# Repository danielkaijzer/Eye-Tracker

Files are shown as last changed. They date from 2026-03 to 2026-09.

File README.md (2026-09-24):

# Eye Tracker

A low-cost, high-precision, low-latency eye tracker prototype. A head-mounted rig pairs an IR eye camera with a forward-facing scene camera. A Python pipeline detects the pupil, calibrates a polynomial mapping from pupil pixels to scene-camera pixels, and renders the gaze locally (OpenCV).

## Platforms

- **Linux (Jetson Orin) is the research rig.** Data collection, time-synced capture and anything that depends on precise timing runs here, and it's the platform the code is developed and tested against.
- **macOS is a live-demo mode.** Plug the headset into a Mac for a quick calibration and live gaze, with no Jetson or external monitor needed. Research features may be missing or degraded there, and CI doesn't cover it, so run a quick calibration before any demo.

## Install

**Linux** (research rig; tested on Jetson Orin, JetPack 6 / Ubuntu 22.04, Python 3.10):

```
sudo apt install libeigen3-dev libopencv-dev cmake python3-dev python3-venv v4l-utils
git clone https://github.com/pupil-labs/pupil-detectors.git ../pupil-detectors
conda create -n et python=3.10 && conda activate et   # or a plain venv
pip install -r requirements.txt                 # builds pupil-detectors + pye3d from source
pip uninstall -y opencv-python                  # pupil-detectors pulls it in; it shadows opencv-contrib-python
pip install --force-reinstall --no-deps opencv-contrib-python==4.13.0.92
```

Your user must be in the `video` group to open `/dev/video*`. Cameras are opened through V4L2 with MJPG. The scene cam is picked by its USB id (`SCENE_UVC_ID` in `config.py`) because each UVC camera shows up as two `/dev/video` nodes. Exposure hotkeys go through `v4l2-ctl`. When launching over SSH, target the attached monitor with `DISPLAY=:0`. The calibration monitor runs at 100 Hz; on the Jetson that mode is persisted in `~/.config/monitors.xml`.

**macOS** (demo mode):

```
brew install eigen opencv                       # system deps for pupil-detectors
git clone https://github.com/pupil-labs/pupil-detectors.git ../pupil-detectors
pip install -r requirements.txt                 # installs the local pupil-detectors clone
```

Optional: scene-cam exposure hotkeys need the `uvc-util` binary (build steps in `requirements.txt`; terminal usage in `docs/uvc_exposure_cheatsheet.md`). Without it the app runs with the camera's default exposure.

**Both:** if the pupil-detectors build fails with `FindCython ... cython;--version failed`, CMake cached a temp build-env path from an earlier failed attempt. Delete `../pupil-detectors/_skbuild` and retry. If it still fails, install the build deps (`pip install setuptools_scm scikit-build cmake ninja cython`) and use `pip install --no-build-isolation ../pupil-detectors`.

`requirements.txt` references `../pupil-detectors` as a local path relative to the repo root; adjust the clone location or edit the path if your layout differs. `pye3d` ships from PyPI (built from source on aarch64).

**Hardware** — head-mounted rig with an IR eye camera and a forward-facing scene camera (USB UVC). Calibration draws four ArUco markers (`DICT_4X4_50`, IDs 0/1/2/3) directly onto the calibration screen.

## Running

```
DISPLAY=:0 python -m scripts.eyetracker         # Linux, in the `et` env (DISPLAY only needed over SSH)
python -m scripts.eyetracker                    # macOS demo
```

### In-app controls (eye tracker window)

| Key | Action |
| --- | --- |
| `c` | Quick calibration (3×3 grid, degree-2 polynomial). During calibration: capture the current point, or start the next pose |
| `d` | Detailed calibration (5×4 grid, degree-3 polynomial, with worst-point recapture) |
| `m` | Multi-pose calibration (one grid per head pose, aggregated into one fit — widens field-of-view coverage; press `c` to start each pose) |
| `v` | Validation capture (collect-only; writes a held-out session tagged `phase: validation` for accuracy measurement, leaves the live calibration untouched) |
| `l` | Load most recent saved calibration |
| `r` | Reset the pye3d 3D pupil model (give it ~30 s to reconverge) |
| `s` / `Esc` | During calibration: skip the current point / abort its capture and retry |
| `p`, `-` / `=` | During calibration: camera preview, marker brightness |
| `[` / `]`, `{` / `}` | Scene exposure darker / brighter, fine / coarse |
| `space` | Pause |
| `q` | Quit |

For why `m` and `v` exist and how to read the accuracy numbers, see
[`docs/calibration_coverage.md`](docs/calibration_coverage.md) and
[`docs/multipose_calibration.md`](docs/multipose_calibration.md).

## Repo layout

```
scripts/eyetracker/         # Main Python package — `python -m scripts.eyetracker`
    __main__.py             # Composition root: wires concrete classes into App
    app.py                  # Main loop, frame routing, key dispatch
    config.py               # All tunables (camera, calibration grid, smoother, ArUco)
    cameras/                # OpenCV camera sources + discovery
    pupil/                  # Pupil Labs detector + confidence/jump gates
    scene/                  # ArUco detection and screen→scene homography
    gaze/                   # Polynomial mapper, 1€ smoother
    calibration/            # State machine, sample collector, persistence
    dataset.py              # Read recorded sessions (metadata.json + labels.csv)
    display/                # Tk calibration overlay, cv2 windows

scripts/extras/             # Standalone utilities
    calibrate_scene_intrinsics.py   # ChArUco intrinsics for the scene camera
    calibrate_eye_intrinsics.py     # ChArUco intrinsics for the eye camera (app frame geometry)
    calibrate_extrinsics.py         # Eye↔scene transform from the calibration jig (hand-eye solve)
    generate_charuco_board.py       # Screen board PNG for the above; printable jig boards (PDF)
    charuco_boards.py               # Board specs shared by the generator and calibration scripts
    measure_gaze_accuracy.py        # Accuracy binned by eccentricity; held-out validation sessions

docs/                       # Implementation notes, citations, architecture
    findings.md                     # What we've measured, decided, or learned (dated)
    polynomial_gaze_mapping.md      # How the pupil→scene fit works end-to-end
    loo_error_notes.md              # Leave-one-out error: what it measures, past regression
    calibration_coverage.md         # The coverage problem + eccentricity validation tooling
    multipose_calibration.md        # Multi-pose calibration: widening FOV coverage
    uvc_exposure_cheatsheet.md      # macOS uvc-util camera controls from the terminal
    data_collection.md              # Fields the data-collection pipeline captures
    dataset_format.md               # On-disk format for sessions + calibration artifacts
    citations/                      # references.bib + references.tex

data/                       # Recorded calibration sessions (gitignored)
3d-files/                   # OpenSCAD camera mounts (see its README)
requirements.txt            # Python deps (OpenCV, numpy, pupil-detectors)
```

## Pipeline

```mermaid
graph TD
    subgraph Hardware ["Head-mounted rig"]
        EYE[IR eye camera] --> CAP[OpenCV capture]
        SCN[Scene camera] --> CAP
    end

    subgraph Pipeline ["Python (scripts/eyetracker)"]
        CAP --> PD[Pupil Labs 2D detector + pye3d]
        PD --> GATE[Confidence + jump gates]
        GATE --> POLY[Polynomial gaze mapper]
        CAP --> ARUCO[ArUco screen-corner detection]
        ARUCO -. calibration only .-> CAL[Calibration routine<br/>screen→scene homography]
        CAL --> POLY
        POLY --> SMOOTH[1€ smoother]
    end

    subgraph Output
        SMOOTH -->|cv2 windows| CV[Display]
    end
```

See [`docs/polynomial_gaze_mapping.md`](docs/polynomial_gaze_mapping.md) for the math behind the pupil→scene fit and why the homography only shows up during calibration.

## Code style

- **Python** — [PEP 8](https://peps.python.org/pep-0008/). Enforced by `flake8` in CI (`.github/workflows/linter.yml`): blocking on `E9`/`F63`/`F7`/`F82` (syntax errors, undefined names), with line length 127 and McCabe complexity 10 as non-blocking warnings. Public-facing modules, classes, and functions carry docstrings.

## Design & architecture

- **External references** — catalogued in [`docs/citations/references.bib`](docs/citations/references.bib)

## Maintainer 

Daniel Kaijzer

## Prior contributors

Cody Lam, Ethan Shim, Harwin He, Roselio Ortega

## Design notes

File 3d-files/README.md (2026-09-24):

# 3D-printed camera mounts

Parametric OpenSCAD designs for the eye and scene camera mounts. Open a `.scad`
file, set `show = ...` near the top, then press F5 to preview or F6 to render and
export an STL. Hardware dimensions are in [MEASUREMENTS.md](MEASUREMENTS.md).

## Current designs (printed and in use)

| Camera | File | Notes |
|---|---|---|
| Eye (UC-844 Rev.B, IR) | [`eye_cam/uc844_mount_v9_DK.scad`](eye_cam/uc844_mount_v9_DK.scad) | Frame + two arms; clamps to the rod with the stock white clips. Needs `clip_ref.stl` in the same folder. |
| Scene (HUAQUE HQ-L103) | [`scene_cam/scene_cam_top_mount_v2.scad`](scene_cam/scene_cam_top_mount_v2.scad) | Backing plate + parametric `rod_clip()`, so no STL import is needed. |

When a new version replaces one of these, move the old file into `archive/`.

## Calibration jig

The eye↔scene extrinsics jig isn't 3D printed. It's three stainless steel sheets held at
roughly 90° with L brackets, with printed ChArUco boards pasted on
(`scripts/extras/generate_charuco_board.py --board print`) so the eye cam and the scene cam
each see a board on a different sheet. The angles don't need to be exact: the extrinsics
solver only needs the jig to be rigid (`scripts/extras/calibrate_extrinsics.py`; its
docstring has the capture workflow). An earlier 3D-printed design was never built; it's in
git history.

## Archive

`archive/` keeps earlier iterations for reference. They aren't maintained.

- `archive/eye_cam/`: `uc844_mount_v1`–`v8`, `glasses_rod_adapter.scad` (the peg
  adapter that v3's integrated clamp replaced), the v6 design notes, and the original Fusion STEP bottom mount.
  v7 and v8 import `../../eye_cam/clip_ref.stl`.
- `archive/scene_cam/`: `scene_cam_top_mount_v1.scad` and the original Fusion
  STEP top mounts (`top_mount_step/`, v1–v3.3).

## Design notes

- 60° seems to be the right angle for the internal eye cam.
- The backs of the mounts should be perforated for airflow. Consider a way to
  add thermal paste to help cool the PCBs.

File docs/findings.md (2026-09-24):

# Findings

What we've measured, decided, or learned the hard way, so it carries across
sessions and machines. One or two lines each, newest first within a section,
with a pointer (→) to the doc or code that holds the detail.

When a finding stops being true, don't delete it: mark it **Superseded** with the
date and what replaced it. "We tried X and it didn't work" is often the most
useful part. Entries marked *unverified* haven't been confirmed on the rig.

## Gaze model and calibration

- 2026-09-24 · Scene cam horizontal FOV is ~54° (fx 1894.7 px at 1920 wide), so
  multi-pose calibration is capped by when a corner marker leaves the frame, not
  by the lens. → `TODO_multipose_coverage.md`
- 2026-09-23 · Calibration labels, fit and live prediction check out (quick
  9-point LOO ~14–28 px). Remaining error is physical: gaze is only exact at the
  calibration depth (eye↔scene parallax), and the pupil-only mapping is very
  slip-sensitive (a ~40 px pupil shift between runs moved gaze ~900 px).
  → `TODO.md` (Accuracy)
- 2026-07-13 · *Unverified:* undistorting marker corners before `findHomography`
  cut geometric error at non-anchor points by ~1.2 px in a synthetic test with the
  real distortion coefficients. → branch `use-intrinsics-for-homography`
- 2026-06-29 · A half-finished hat-matrix LOO refactor once returned all-zero LOO
  errors, silently breaking recapture targeting and accuracy reports.
  → `docs/loo_error_notes.md`, `tests/test_polynomial_loo.py`
- 2026-06-06 · **Decision:** the roadmap is polynomial → CNN (eye image in, gaze
  point out), with no 3D-model step. First, data collection whose sessions stay
  usable across rig changes.
- Before 2026-06 · Polynomial ceiling: a narrow central grid gave 0.39° avg /
  0.94° max LOO; a wider grid made the fit worse everywhere (~1.56° avg). Don't
  tune the polynomial (degree, grid size, point count). → `docs/calibration_coverage.md`
- Standing · Benchmark: Pupil Labs Neon, ~0.5–1° (model-based, multi-glint, slip
  correction).

## Cameras

- 2026-09-24 · The app center-crops eye frames to 4:3 and resizes them to 640x480
  before pupil detection, so pupil coordinates and saved eye images are 640x480 in
  any mode. But the eye cam's native mode isn't requested (driver default), and
  `EYE_CAM_FOV_DEG` (80°) is the old Sonix lens; it feeds pye3d's focal length and
  `metadata.json`. → `config.py`, `TODO.md`
- 2026-09-24 · Eye cam illumination: one hand-soldered IR LED above the lens
  (off-axis): dark pupil, single glint, no retroreflection. → `3d-files/MEASUREMENTS.md`
- 2026-09-23 · OV9281 manual exposure works over UVC on Linux (0.5–9.9 ms
  verified). In auto mode it doesn't report the exposure it picked.
  → `docs/timestamping.md` (on branch `timestamping`)
- 2026-07-15 · OV9281 caps at 120 fps in every mode (MJPG 320x240 to 1280x800 at
  100/120 fps; YUYV only 10 fps; no 30 fps mode). Faster needs other hardware.
- 2026-07-15 · Trap (macOS): `ffmpeg -f avfoundation` "negotiates" 120 fps but
  delivers ~83. Always measure delivered fps.
- 2026-07-15 · The OV9281 reuses the Sonix bridge's USB id `0x0c45:0x6366`; tell
  them apart by serial (UC762). Camera indexes shift between enumerations, so
  select cameras by USB id, not index.
- 2026-06-28 · The scene cam (Realtek OV5640) is manual-exposure only;
  `exposure-time-abs` is the real brightness lever and `gain` only scales output.
  → `docs/uvc_exposure_cheatsheet.md`
- **Superseded 2026-06-28** · "Scene exposure-time is cosmetic." It was tested in
  auto mode, where UVC ignores exposure writes.
- **Superseded 2026-09** · "The eye cam's exposure can't be controlled." True only
  of the retired Sonix GC0308, whose auto-exposure ran internally.
- 2026-06-08 · uvc-util reports success even when a camera ignores or clamps a
  write, so every set is read back. On macOS, OpenCV can't set exposure at all.
  → `cameras/uvc_util.py`

## Timing and sync

- 2026-09-23 · Eye−scene timestamp offset (flash test): 4.8 ms, ±0.3 ms run to
  run, ~±2 ms systematic. Rerun if exposure or cameras change.
  → `docs/timestamping.md` (on branch `timestamping`)
- 2026-09-23 · The 5.15 kernel's UVC hardware timestamps are broken for the eye cam
  (its bridge reports a free-running counter; stamps drifted ~2600 ppm and jumped
  >100 ms), so PTS/SCR are converted in userspace. → `docs/timestamping.md`
  (on branch `timestamping`)
- 2026-09 · Without a grabber thread, V4L2 hands back the oldest queued frame: eye
  frames were 130–275 ms stale on the Jetson. → `cameras/opencv_source.py`
- 2026-09-24 · **Decision:** no streaming the rig's video to another machine for
  calibration or display for now. Calibration-dot onsets would then happen on a
  different machine's clock, bringing back the cross-machine sync problem.
  (`linux_cam_stream.py` removed; it's in git history.)
- 2026-09 · **Decision:** research capture runs on Linux. On macOS, raw UVC
  timestamps need root and exclusive device access, which rules out OpenCV
  capture. macOS stays a live-demo mode. → `README.md` (Platforms)

## Calibration jig and rig geometry

- 2026-09-24 · Synthetic check of the hand-eye extrinsics solve: exact recovery on
  clean data; 0.29° / 2.3 mm error with 0.2° / 0.5 mm per-pose noise over 20 pairs.
  → `tests/test_extrinsics_solve.py`
- 2026-09-24 · Eye-side board: at eye distance (~45–50 mm) 5 mm squares give
  45–113 ChArUco corners per frame in a synthetic render, vs ~6 for 15 mm squares.
  Refocusing the M12 lens changes the intrinsics by a few percent, so calibrate at
  eye focus. The print dictionary has only 1000 marker IDs, so board sizes are
  capped. → `scripts/extras/charuco_boards.py`, `tests/test_charuco_boards.py`
- 2026-09-24 · *Unverified:* many inkjet inks are nearly invisible in IR, so
  laser-print boards the eye cam must see.
- 2026-09-24 · **Decision:** the 3D-printed jig was abandoned for three stainless
  steel sheets at ~90° with pasted ChArUco boards. The hand-eye solve only needs
  the jig rigid, not measured. → `3d-files/README.md`, `calibrate_extrinsics.py`
- 2026-05 · Tape-measured camera offsets: ~50 mm lateral, 13 mm depth, 50 mm
  vertical (~72 mm baseline), on the old mounts. Re-measure before relying on them.

## Data

- 2026-09-24 · The pre-migration calibration history (27 Sonix-era sessions, 352
  pupil/target pairs, no images) is kept only on the Mac at `data/legacy/`, not in
  git.
- 2026-06-06 · Persistence moved off `.npz` to JSON + CSV (`calibration.json`,
  per-session `metadata.json` + `labels.csv`). → `docs/dataset_format.md`

## Scope

- 2026-09-24 · **Decision:** no frontend until the tracking fundamentals work. The
  paused Next.js dashboard and its tools were removed (they're in git history).

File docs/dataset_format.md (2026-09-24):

# Dataset & calibration on-disk format

The pipeline records calibration/collection sessions as a **dataset of record** for
later analysis and CNN training. Each artifact uses the format that fits its job —
JSON for small structured/provenance data, CSV for append-during-capture sample
rows, image files for frames, Parquet only at consumption time.

## Layout

```
data/calibration/
  session_<ts>/
    metadata.json            # per-session record (intrinsics, extrinsics, provenance)
    labels.csv               # one row per accepted sample
    fixNN_sampleNN.png       # eye-cam frame
    fixNN_sampleNN_scene.png # scene-cam frame
  combined.parquet           # planned: cache for whole-dataset training loads
scripts/eyetracker/
  calibration.json           # live polynomial model restored at runtime
  scene_intrinsics.json      # scene-cam intrinsics (K, dist)
  eye_intrinsics.json        # eye-cam intrinsics, in the app's cropped 640x480 frames
rig_calibrations/
  <rig_id>.json              # written by scripts/extras/calibrate_extrinsics.py
```

## Artifacts

### `calibration.json` — the live model
Just what the runtime needs to restore the mapper. Raw samples are **not** stored
here; they live in the source session's `labels.csv` (named via `source_session`).

```json
{ "coord_space": "scene", "timestamp": 0.0, "source_session": "session_<ts>",
  "scene_size": [w, h], "screen_size": [w, h],
  "model": { "type": "polynomial", "degree": 2, "coeffs_x": [...], "coeffs_y": [...] } }
```

### `session_<ts>/metadata.json` — the dataset record
Self-contained: each session inlines a snapshot of the active intrinsics/extrinsics
so it stays interpretable even if the cameras or central calibration files change.
Fields the pipeline does not yet produce are `null` placeholders (filled later by the
extrinsics jig and richer per-frame capture).

```json
{ "session_id": "session_<ts>", "created_at": "<iso>", "timestamp": 0.0,
  "phase": "calibration",
  "subject_id": null, "glasses": null, "headset_model_version": null, "kappa_deg": null,
  "software": { "pupil_detector": null, "pye3d": null, "app_git_sha": null },
  "screen":   { "width": w, "height": h },
  "scene_cam":{ "width": w, "height": h, "fps": null, "identifier": null },
  "eye_cam":  { "width": w, "height": h, "fps": null, "fov_deg": 80.0, "identifier": null },
  "aruco":    { "dict_name": "...", "dict_id": n, "marker_px": n, "quiet_zone_px": n,
                "ids": [...], "screen_centers": [[x, y], ...] },
  "superseded_fixation_ids": [],
  "rig_calibration_id": null,
  "intrinsics": { "eye": null, "scene": { "K": [[...]], "dist": [...], "reproj_rms": n } },
  "extrinsics": null,
  "fit": { "degree": 2, "n_points": n, "loo_avg_px": n, "loo_max_px": n } }
```

### `labels.csv` — per-sample ground truth
Columns (see `LABELS_CSV_HEADER` in `calibration/persistence.py`):
`image_path, fixation_id, x_screen, y_screen, pupil_x, pupil_y, confidence,
timestamp, scene_target_x, scene_target_y`. Appended row-by-row during capture so a
mid-session crash keeps what was already written. `fixation_id` is unique within a
session (one per capture attempt, so rejected/aborted attempts leave gaps) and
names the images (`fix<id>_sample<n>.png`). A screen point can appear under
several ids: once per pose in multi-pose, and twice when the detailed routine
recaptures it. `metadata.json`'s `superseded_fixation_ids` lists the pass-1
ids a recapture replaced; drop them to reproduce the live fit. Sessions from
before 2026-09-23 reused ids across poses/recapture passes (and overwrote those
images), so their `fixation_id` is unreliable there. Richer per-frame fields
(ellipse params, pye3d 3D vectors, normalized-image paths) from
`docs/data_collection.md` are added as the pipeline starts producing them.

### `rig_calibrations/<rig_id>.json` — camera-rig calibration (planned)
Written by `scripts/extras/calibrate_extrinsics.py` from a jig capture. Sessions don't
reference it yet: `rig_calibration_id` and `extrinsics` in `metadata.json` are still
null (see `TODO.md`).

```json
{ "rig_id": "<ts>", "created_at": "<iso>", "notes": null,
  "intrinsics": {
    "eye":   { "K": [[...]], "dist": [...], "image_width": 640, "image_height": 480,
               "reproj_rms": r, "source": "eye_intrinsics.json" },
    "scene": { ...same keys... } },
  "extrinsics_eye_to_scene": {
    "R": [[...]], "t": [...], "units": "mm", "method": "calibrateRobotWorldHandEye/SHAH",
    "residual_rot_deg": { "mean": x, "max": x }, "residual_trans_mm": { "mean": x, "max": x } },
  "capture": { "n_pairs": n, "pose_diversity_deg": x, "eye_board": "small",
               "scene_board": "large", "board_b_to_a": { "R": [[...]], "t": [...] } } }
```

`extrinsics_eye_to_scene` maps eye-cam coordinates to scene-cam coordinates:
`p_scene = R @ p_eye + t`, in mm. The intrinsics are copied in so the record is
self-contained; the eye intrinsics describe the app's processed eye frames (4:3 crop,
resized to 640x480), not the camera's native mode.

## Loading for analysis / training

`scripts/eyetracker/dataset.py`:
- `load_session(dir) -> (metadata, DataFrame)` — one session.
- `session_dirs(root)` — list every `session_<ts>/` under a root.

Planned (TODO in `dataset.py`, build with the CNN training loop): `load_all` to
concatenate all sessions + cache `combined.parquet`, and an image-loading layer that
joins each row's `image_path` to its eye frame.

`scripts/extras/measure_gaze_accuracy.py --session <dir>` refits the polynomial from
a session and reports LOO error in px and degrees.

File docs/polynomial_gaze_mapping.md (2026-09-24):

# Polynomial Gaze Mapping

How we turn a pupil pixel from the eye camera into a gaze pixel in the scene camera.

## Goal

Given a pupil center `(px, py)` in eye-camera pixels, predict where in the scene-camera image the user is looking — `(scene_x, scene_y)`.

## Why a polynomial?

The eye is a sphere, the cornea bulges, the eye camera sits at an off-axis angle, and the pupil moves on a curved manifold as gaze sweeps the world. The mapping `(px, py) → (scene_x, scene_y)` is not linear, but over the limited range of pupil motion it is smooth and well-approximated by a low-degree polynomial.

We use a 2nd-degree bivariate polynomial. The feature row (`_build_features` in `scripts/eyetracker/gaze/polynomial.py`) is:

```
φ(px, py) = [1, px, py, px², py², px·py]
```

Six terms, so:

```
scene_x = a₀ + a₁·px + a₂·py + a₃·px² + a₄·py² + a₅·px·py
scene_y = b₀ + b₁·px + b₂·py + b₃·px² + b₄·py² + b₅·px·py
```

Two completely independent fits — one for `x`, one for `y`. 12 unknowns total (6 per axis).

This doc walks through degree 2, which quick calibration (`c`) uses. Detailed (`d`) and multi-pose (`m`) calibration use degree 3 (10 terms per axis, cubic terms added); the same reasoning applies with 10 in place of 6.

### 6 coefficients vs. 9 calibration points

A potential point of confusion: quick calibration (`c`, `CALIB_QUICK_*` in `scripts/eyetracker/config.py`) is a 3×3 grid = **9 fixation targets**, but each polynomial only has **6 coefficients**. Why so many points if there are only 6 unknowns?

Because we are *deliberately overdetermined*. Each fixation gives one `(px, py) → scene_x` equation and one `(px, py) → scene_y` equation. With 9 fixations we have 9 equations per polynomial in 6 unknowns — more equations than unknowns. There is generally no exact solution; instead `np.linalg.lstsq` finds the 6 coefficients that minimize the total squared error across *all* 9 points simultaneously.

The 3 extra equations are not waste, they are noise averaging:

- The pupil center is noisy (per-frame jitter, ellipse fitting variance).
- The ArUco-derived label is noisy (marker detection shake).
- The user does not fixate perfectly.

If we used exactly 6 points, the polynomial would pass through every label exactly — including their noise. Those 6 coefficients would chase noise instead of true geometry, and predictions on new pupil positions would be worse. With 9 points the fit is forced to compromise, which pulls it toward the *underlying* pupil-to-scene relationship.

The hard minimum is 6 points (the `n < 6` guard). Below that the system is underdetermined — infinitely many polynomials fit. Above 6, more is generally better up to a point of diminishing returns.

## What calibration collects

For each fixation point we need a pair:

- **Input**: pupil center `(px, py)`, median-filtered over a small per-fixation buffer (`SampleCollector` in `scripts/eyetracker/calibration/collector.py`).
- **Label**: where that fixation target actually appeared in the scene-cam image.

The label is the tricky part — that's where the homography enters.

## Where the homography fits in

We show a red dot at screen-pixel `(tx, ty)` on a monitor. The scene camera knows nothing about the screen — it just sees a 2D image of the world. We need to know: "the dot is at screen-pixel `(tx, ty)`; where in the scene-cam frame is that point right now?"

A flat screen viewed from an arbitrary angle becomes a quadrilateral in the camera image. The screen-plane → camera-image mapping is exactly a **homography** — a 3×3 matrix in projective coordinates.

Four ArUco markers are pinned at the screen corners. In `ArucoHomography._homography_from` (`scripts/eyetracker/scene/aruco_homography.py`):

```python
H, _ = cv2.findHomography(screen_pts, scene_pts, method=0)
```

- `screen_pts` — the 4 marker centers in screen pixels (we drew them, so we know exactly where).
- `scene_pts` — the 4 marker centers detected in the scene-cam image.

OpenCV solves for the 3×3 `H` such that for any screen point `(tx, ty)`:

```
[u·w, v·w, w]ᵀ = H · [tx, ty, 1]ᵀ
scene_u = u·w / w
scene_v = v·w / w
```

That projection happens in `CalibrationRoutine.tick()` (`scripts/eyetracker/calibration/routine.py`). We recompute `H` on every calibration frame because the user's head moves and the screen-to-scene projection drifts. The resulting `(target_u, target_v)` is the "ground truth" scene-cam pixel for each pupil sample.

## The calibration loop

For each fixation:

1. User stares at the red dot at screen-pixel `(tx, ty)`.
2. Pupil pipeline gives us `(px, py)`.
3. ArUco gives us `H` for this frame.
4. `(target_u, target_v) = H · (tx, ty)` — the dot's location in scene-cam pixels.
5. Median-filter both over a few frames (`SampleCollector`) to get one clean `(pupil_median, scene_median)` pair.

After all accepted fixations (9 from the quick grid, fewer if the user skipped any) we have matched arrays of `pupil_pts` and `scene_pts`.

## The fit

In `PolynomialGazeMapper.fit()` (`scripts/eyetracker/gaze/polynomial.py`): build the design matrix `A` (n rows × 6 columns, each row is `φ(px, py)`), and target vectors `bx` (n scene-x labels) and `by` (n scene-y labels). Solve two least-squares problems:

```python
cx, _, _, _ = np.linalg.lstsq(A, bx, rcond=None)   # 6 coeffs for scene_x
cy, _, _, _ = np.linalg.lstsq(A, by, rcond=None)   # 6 coeffs for scene_y
```

`np.linalg.lstsq` minimizes `||A·c − b||²` — closed-form, no iteration. With 9 points and 6 unknowns the residual sum of squares has 3 degrees of freedom (n − p = 9 − 6), which is what lets the fit average out per-point noise instead of memorizing it. The hard minimum is 6 points (the `n < 6` guard); below that the system is underdetermined.

## Leave-one-out error

Also in `PolynomialGazeMapper.fit()`: refit using `n−1` points, predict the held-out one, measure pixel error in scene-cam space. Average and max over all `n` rounds. This is more honest than training residuals — with 6 unknowns and only 9 points, training residuals would underestimate true error because the fit is close to interpolating its own training set.

## Prediction at runtime

After calibration the homography is gone — it did its job (labeling) and is no longer needed. At runtime (`PolynomialGazeMapper.predict()`):

```python
feat = [1, px, py, px², py², px·py]
scene_x = feat · coeffs_x
scene_y = feat · coeffs_y
```

12 multiply-adds per frame. The polynomial takes pupil pixels and gives scene-cam pixels directly — no homography at inference, because calibration baked the geometry into the polynomial coefficients.

## Mental model

- **Polynomial** — "given a pupil pixel, where is the gaze in the scene cam?" The model used forever after calibration.
- **Homography** — "given the dot on the screen, where is it in the scene cam right now?" Only used during calibration to manufacture training labels. It's what turns "look at this screen pixel" into "the eye is fixating that scene pixel."

If the user moves their head, the homography changes (the screen appears somewhere different in the scene cam), but the polynomial doesn't care. Pupil-pixel-to-scene-cam-pixel is a property of how the eye + cameras are rigged together on the headset, invariant to where the user is standing.

The one assumption currently baked in: the eye and scene cameras are fixed relative to each other (head-mounted rig). If the rig flexes, the polynomial drifts and recalibration is needed.

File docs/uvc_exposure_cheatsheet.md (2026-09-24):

# UVC camera control cheat sheet (macOS)

Quick reference for driving the rig's cameras with **uvc-util** from the command
line, independent of the app. OpenCV/AVFoundation can't set exposure on macOS, so
this is the only working path. On Linux, use `v4l2-ctl` instead.

## Setup

The binary lives at `/opt/homebrew/bin/uvc-util` (on PATH). Every command selects
a camera by its USB **vendor:product** id (stable across replug, unlike the index):

```bash
B=/opt/homebrew/bin/uvc-util
SCENE="--select-by-vendor-and-product-id=0x0bda:0xd565"   # Realtek bridge / OV5640
EYE="--select-by-vendor-and-product-id=0x0c45:0x6366"     # Arducam OV9281 (was Sonix GC0308)
```

List what's connected / what a camera supports:

```bash
$B -d                       # list all UVC devices with their vendor:product ids
$B $SCENE -c                # list controls this camera implements
$B $SCENE -S exposure-time-abs   # show range/default for one control
$B $SCENE -S '*'            # show range/default for ALL controls
```

> **Heads-up:** `-s` (set) returns success even when the camera silently ignores
> or clamps the write. Always confirm with `-g` (get).

---

## Scene camera (`0x0bda:0xd565`)

This is the one that matters for ArUco. **`exposure-time-abs` is the real lever**
(it drives sensor integration time); `gain` only scales output luminance and adds
noise. This module is **manual-only** — it accepts no auto-exposure mode.

| Control | Range | Default | What it does |
|---|---|---|---|
| `exposure-time-abs` | 1–10000 | ~332 | sensor integration time — **the lever** |
| `gain` | 0–128 | 64 | output luminance + noise |
| `auto-exposure-mode` | 1 only | — | manual-only; auto writes revert to 1 |

```bash
# Read current state
$B $SCENE -g exposure-time-abs
$B $SCENE -g gain

# Make sure it's in manual (required for exposure-time to take effect)
$B $SCENE -s auto-exposure-mode=1

# Set exposure time (lower = darker/sharper, higher = brighter/more motion blur)
$B $SCENE -s exposure-time-abs=400

# Reset gain to a sane value (it persists wherever you last left it — the app
# doesn't touch it). 64 is the device default; lower = darker + less noise.
$B $SCENE -s gain=64
```

**Fixing blown-out ArUco markers** (the original problem): markers blow out when
exposure is too high. Drop `exposure-time-abs` until the white quiet-zone stops
clipping, keep `gain` moderate (lower = cleaner edges for detection):

```bash
$B $SCENE -s auto-exposure-mode=1
$B $SCENE -s gain=32
$B $SCENE -s exposure-time-abs=250   # tune down until markers are crisp, not glowing
```

---

## Eye camera (`0x0c45:0x6366`)

The eye cam is now the **Arducam OV9281** (serial UC762). It reuses the old Sonix
GC0308 module's VID:PID, so `$EYE` selects whichever one is plugged in. Unlike
the Sonix, the OV9281 implements the full UVC exposure set: `exposure-time-abs`
(units of 100 µs, range 1–5000, default 157), `auto-exposure-mode` (default 8 =
aperture priority) and `gain`, all read-back verified.

```bash
$B $EYE -s auto-exposure-mode=1        # manual
$B $EYE -s exposure-time-abs=50        # 5 ms
$B $EYE -g exposure-time-abs
```

(The retired Sonix module ran its auto-exposure internally and ignored these
writes; only `gain` had any effect.)

---

## In-app hotkeys

The app drives the **scene cam's** `exposure-time-abs` live (the eye cam is not
driven from the app — use the terminal commands above for it):

| Key | Action |
|---|---|
| `[` / `]` | darker / brighter — **fine** step (~10 units) |
| `{` / `}` | darker / brighter — **coarse** step (~500 units) |

On-screen readout shows e.g. `scene:exp 400`.

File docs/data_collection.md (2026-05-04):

# Data I want to Collect during calibration sequence and clicking game

- Camera intrinsics inluding
    - focal + principal point
    - distortion coefficients
- Camera extrinsics (via custom jig before the session recording)
- Depth/vector from eye to eye-camera optical center
- Estimated eye center
- 2D pupil estimates; raw ellipse params (center, axes, angle) + detector confidence per frame
- Estimated 3D vector from eye center to pupil center (via pye3d); gaze direction
    - Also normalized unit vector
- scene gaze point x,y
- Eye camera image with timestamp (original and normalized)
- Scene camera image with timestamp (original and normalized)
- Ground truth pixel location
- Vector from ground truth pixel to scene camera optical center
- ArUcO locations
- phase tag (calibration vs clicking game vs optical flow)
- subject ID
- glasses enum (glasses vs contacts vs nothing)
- headset model version
- per-subject kappa angle
- py3d version
- pupil_detector version

For clicking game:
- click_pixel_x
- click_pixel_y
- click_timestamp

Maybe (if I add these sensors):
- Depth sensor data (for distance) timestamped
- IMU sensor (for pose) timestamped

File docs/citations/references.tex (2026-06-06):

\documentclass[11pt]{article}

\usepackage[margin=1in]{geometry}
\usepackage{hyperref}
\usepackage[backend=bibtex,style=numeric,sorting=nyt]{biblatex}

\addbibresource{references.bib}

\title{Eye Tracker --- External References}
\author{Daniel Kaijzer}
\date{05/21/2026}

\begin{document}
\maketitle

This document lists external contributions --- libraries, algorithms,
tutorials, and AI tools --- that influenced the eye-tracker project. Dependency-manager packages (those listed in
\texttt{requirements.txt} and \texttt{package.json}) are not enumerated
here unless their algorithm or paper is directly load-bearing.

\nocite{*}
\printbibliography[heading=none]

\end{document}

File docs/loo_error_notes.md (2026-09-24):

# Leave-one-out (LOO) error — notes, past regression, and caveats

Working notes on the calibration LOO error: what it's for, a regression that
briefly broke it, and the caveats that are still live. For the conceptual
mapper/LOO walkthrough see [polynomial_gaze_mapping.md](polynomial_gaze_mapping.md).

## Status (2026-06-29)

**LOO is currently implemented correctly.** `PolynomialGazeMapper.fit()`
(`scripts/eyetracker/gaze/polynomial.py`) computes a real leave-one-out error
in its per-point refit loop. A quick check confirms it returns non-zero errors on
noisy data (see the regression test at the bottom). This doc is a record so the
regression below doesn't silently return.

## What LOO is and why it matters here

For each calibration point *i*: refit the polynomial on the other *n*−1 points,
predict the held-out point *i*, and measure the reprojection error in scene-cam
pixels. Averaged (and max'd) over all *n* points, plus a per-point array.

It's used for three things — none of which affect the live fit/predict (those use
the full-data `lstsq` coefficients), but all of which are calibration *quality*
machinery:

1. **Recapture targeting** — the detailed routine's two-pass mode picks the
   worst-N fixations to re-prompt via `np.argsort(per_point_errs)`
   (`_begin_pass_two` in `scripts/eyetracker/calibration/routine.py`).
2. **Quality reporting + warning gate** — `_report_and_save` prints
   `LOO error: avg/max` and warns if `loo_avg_err` exceeds ~4% of scene width.
3. **Accuracy measurement** — `scripts/extras/measure_gaze_accuracy.py`
   reports avg/max/per-point LOO in px and degrees.

(`persistence.py` does **not** record LOO metrics — it saves the polynomial
coefficients via `state_dict`. So a LOO regression does not corrupt saved
calibrations, only the reporting/recapture.)

## The regression that happened

At one point `fit()` was reduced to a stub:

```python
errors = np.zeros(n)          # <-- the real refit loop had been removed
return FitReport(..., loo_avg_err=0.0, loo_max_err=0.0, per_point_errs=errors)
```

It slipped in during the degree-2/3 refactor: the intent (a `TODO` at the top of
the file) was to replace the O(n) refit loop with the hat-matrix shortcut, but
only the zeros stub landed and got committed. The fit itself stayed correct, so
tracking worked — the breakage was invisible except in the quality machinery.

### Blast radius while stubbed

- **Recapture re-prompted the wrong points.** `np.argsort([0,0,…,0])` is
  `[0,1,…,n-1]`, so "worst N" was always the *last* N captured fixations
  (row-major → bottom-right of the grid), regardless of actual error. Two-pass
  refinement was effectively choosing arbitrary points. Note `_should_run_pass_two`
  guards on `per_point_errs is None`, but a zeros array isn't `None`, so pass two
  still ran — on garbage selection.
- **Reported accuracy was a lie** — every calibration printed `avg=0.0px,
  max=0.0px`.
- **The high-error warning was dead** — `0 > err_threshold` is never true.
- **`measure_gaze_accuracy.py` reported 0.000px / 0.00°** and all-zero per-point
  errors. Any ~0.39° figure on record predates the stub.

## The fix (now in place)

The explicit refit loop, degree-agnostic (uses the design matrix `A` as built):

```python
errors = np.zeros(n)
for i in range(n):
    A_loo = np.delete(A, i, axis=0)
    cx_loo, *_ = np.linalg.lstsq(A_loo, np.delete(bx, i), rcond=None)
    cy_loo, *_ = np.linalg.lstsq(A_loo, np.delete(by, i), rcond=None)
    errors[i] = math.hypot(A[i] @ cx_loo - bx[i], A[i] @ cy_loo - by[i])
```

## Remaining caveats (still live)

1. **LOO is meaningless when `n == k`** (`k` = feature count: 6 for degree 2, 10
   for degree 3). The refit drops to `n−1 = k−1` rows < `k` columns →
   underdetermined; `lstsq` returns a min-norm solution (no crash) but the LOO
   number is junk. `fit()` only guards `n >= k`, so LOO is only trustworthy at
   `n >= k + 1`. The configured grids are all comfortably above this (quick 9-12
   vs 6, detailed 20 vs 10, multipose 3×12 vs 10), and `_should_run_pass_two`
   keeps `n` above the minimum after a recapture drop — so it doesn't bite today.
   If a smaller grid is ever configured, consider skipping LOO (leave zeros) when
   `n <= k` rather than reporting a misleading value.

2. **Performance: O(n) refits.** Each `fit()` does `2n` extra `lstsq` solves.
   For n ≤ ~36 this is microseconds — not worth optimizing now. The closed-form
   alternative (the old `TODO`) uses the hat matrix `H = A (AᵀA)⁻¹ Aᵀ`: the LOO
   residual is `residual_i / (1 − h_ii)`, so one fit + the leverages `h_ii` gives
   all per-point LOO errors with no refitting. Revisit only if grids get large.

## Guard against recurrence

A minimal regression test (LOO must be non-zero on noisy quadratic data):

```python
import numpy as np
from scripts.eyetracker.gaze.polynomial import PolynomialGazeMapper

rng = np.random.default_rng(0)
pupil = rng.uniform(-1, 1, (12, 2))
scene = np.column_stack([
    3 + 2*pupil[:, 0] - pupil[:, 1] + 0.5*pupil[:, 0]**2,
    1 - pupil[:, 0] + 2*pupil[:, 1] + 0.3*pupil[:, 1]**2,
]) + rng.normal(0, 0.05, (12, 2))

rep = PolynomialGazeMapper(degree=2).fit(pupil, scene)
assert rep.loo_avg_err > 0 and np.any(rep.per_point_errs > 0), "LOO is stubbed!"
```

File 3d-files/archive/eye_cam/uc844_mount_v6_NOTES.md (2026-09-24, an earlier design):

# v6 (uc844_mount_v6_arm.scad) — status & next steps

3-part eye-cam mount: **frame** + **arm** + **reused white clips**. Keeps v5's aim
pose; splits into separate prints; clips go to the sides (off the lens axis).

## Done / working
- Frame at v5 pose (reuses `frame_body()`): `echo` reports **lens tip 30.0 mm from
  pupil, axis 38° vs 38.1° needed** — aimed at the pupil.
- Eye / rod / gaze-ray mocks kept + a **70° FOV cone** mock; side view confirms the
  cone (camera view) clears the arm, clips and rod (all sit below the upward view).
- Arm reworked to attach at the frame's **bottom edge** (two lugs) and run up to the
  clips — this keeps it **below the FOV** and stops it crossing the board/PCB (the
  earlier top/back attach routed a strut through the PCB window).
- Arm is one printable piece (two struts + bottom cross-brace); clip-ears carry the
  Ø3.2 clip holes at the ~18.7 mm clip pitch.
- `show` = `assembly | exploded | frame | arm`.

## Update — joint + printability pass
- **Frame + arm both manifold** (CGAL Simple: yes). Aim unchanged: tip→pupil 30.0 mm,
  38° vs 38.1° needed.
- **Arm remodeled as a single FLAT PLATE** (was round struts) lying in the tilted
  plane through the clip-ears + frame pads → lays flat on the bed, prints without
  support. Hangs below the lens/FOV.
- **Frame prints flat** pocket-up; the two bottom lugs are in-plane (print flat too).
- **Bolt joint**: each frame lug and its arm pad share a coaxial hole along the frame
  normal → M2.5 bolt + nut laps them (thin lugs, no insert needed). Verified coaxial.
- `show="print"` lays both parts out (arm preview rotation still cosmetically off).

## Next steps (in order)
0. Cosmetic: fix `show="print"` arm rotation to sit truly flat (part already is flat).
1. **Re-render** side/front/iso after the bottom-attach rework; confirm no strut↔board
   collision and FOV still clear. Run CGAL manifold check on `frame` and `arm`.
2. **Clip interface (critical):** the clip-ear is currently a placeholder tab. Extract
   the exact ear geometry the existing white clips bolt to from
   `3d-files/bottom mount/v1 various internal eye cams.step` (Ø3.2 holes 18.7 mm
   apart, ~45° face, ear thickness) and match it; import a clip STL into the assembly
   render to visually confirm they mate. Fallback: design a fresh clip for the
   2.75×5 mm rod.
3. **Arm rigidity/joint:** firm up the frame-lug↔arm joint (single-lap Y-screw into an
   insert in the frame lug). Consider gusseting the struts. Decide adjustable
   (short arc slot at the lug for a few °) vs fixed (emit 30/40/50° variants like the
   originals). User: stability first, adjustability nice-to-have.
4. **USB clearance:** check the bottom lugs/arm don't block the PCB back USB connector
   (bottom-left) or its cable exit.
5. **Export STLs** (`frame`, `arm`), then physical test-fit: bolt arm to the existing
   clips on the rod, aim on the live feed.

## Key params (uc844_mount_v6_arm.scad)
`tilt_angle=38`, `px=-4.8`, `pz=-19.6` (pose → 30 mm standoff); `eye_depth=19`,
`eye_rise=27`; `clip_pitch=18.7`; `ear_pitch=18`; `lug_h=7`. Pose math + `echo` at
top of file.

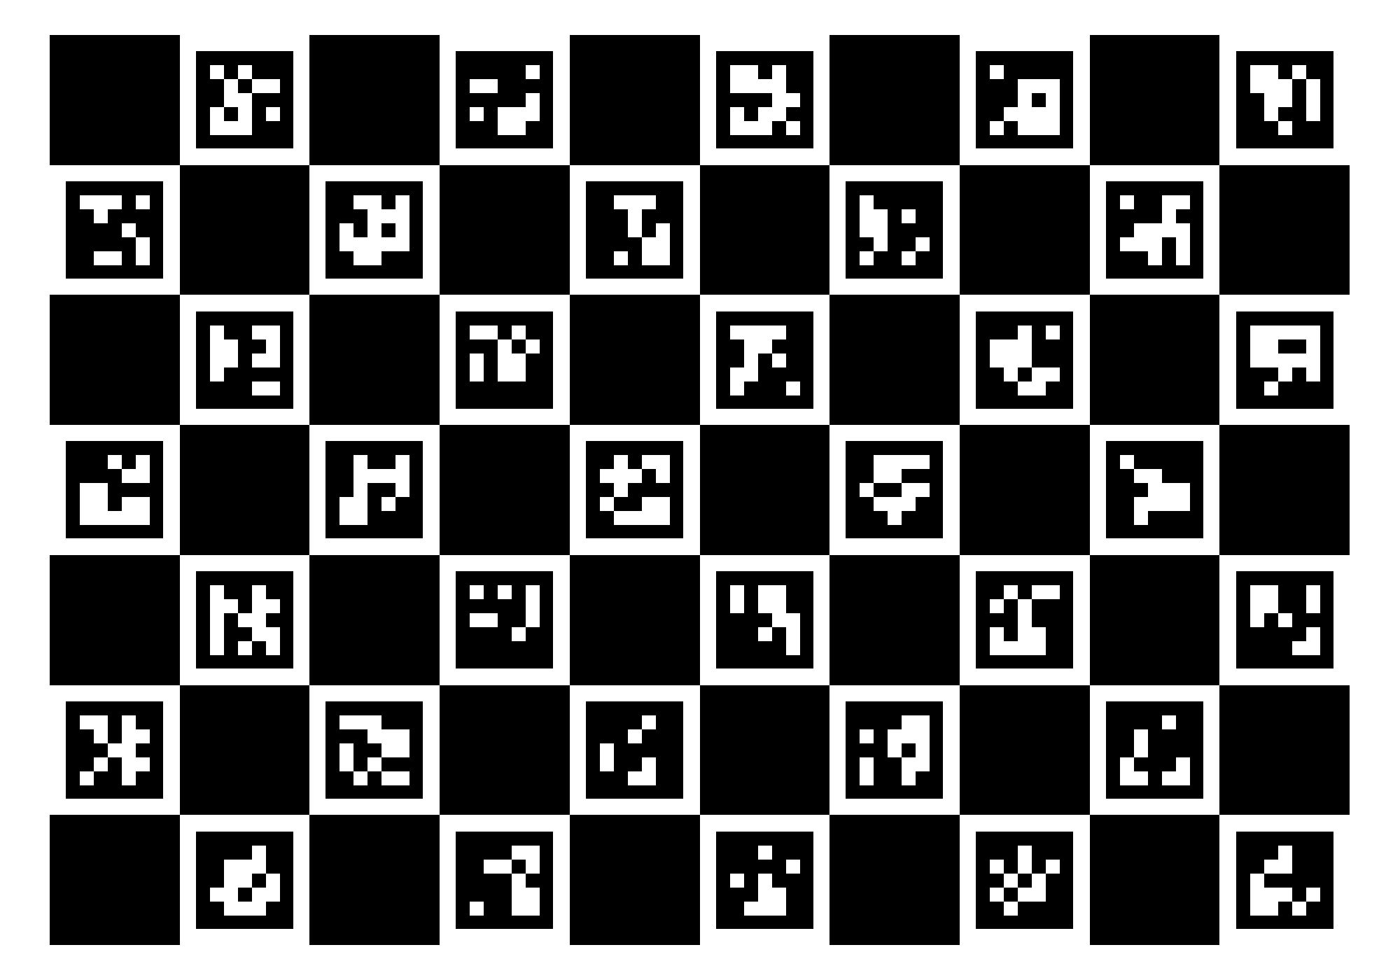
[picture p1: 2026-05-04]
scripts/extras/charuco_board.png

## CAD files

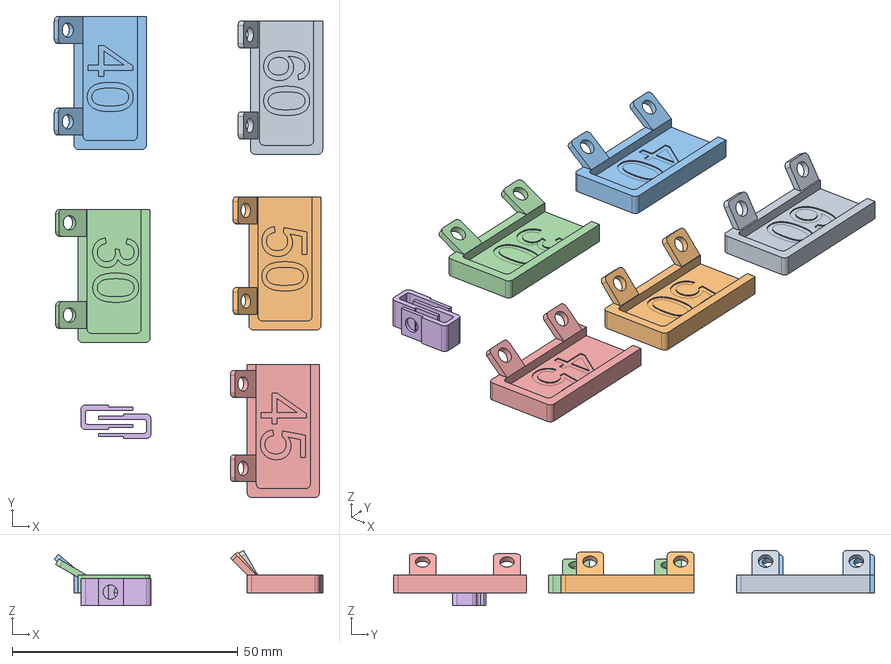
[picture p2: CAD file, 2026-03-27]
3d-files/bottom mount/v1 various internal eye cams.step
59.5 x 106.6 x 12.2 mm
Linear Pattern 12
Linear Pattern 11
Linear Pattern 10
Linear Pattern 09
Linear Pattern 07
Linear Pattern 02

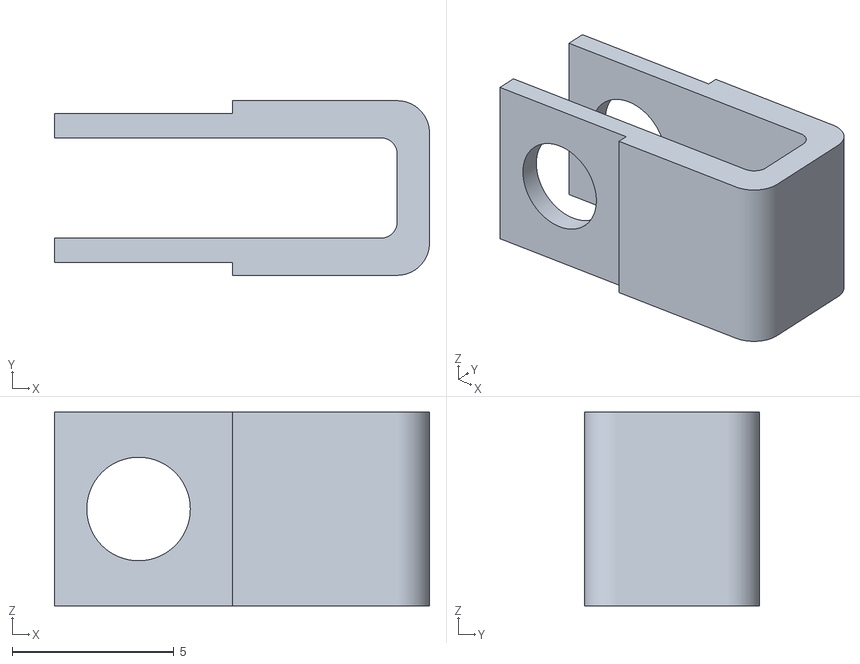
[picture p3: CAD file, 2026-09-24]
3d-files/eye_cam/clip_ref.stl
11.6 x 5.40 x 6.00

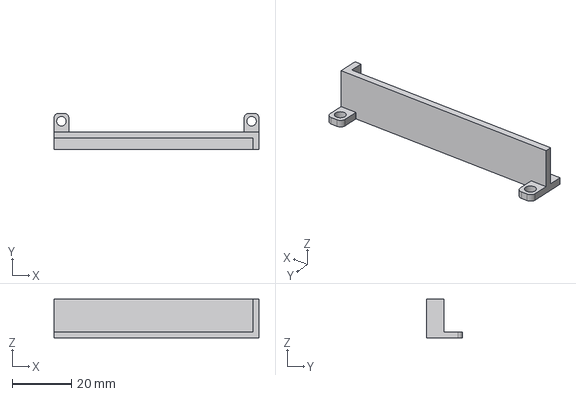
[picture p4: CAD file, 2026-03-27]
3d-files/top mount/v3.1 bar.step
69.0 x 12.2 x 13.0 mm

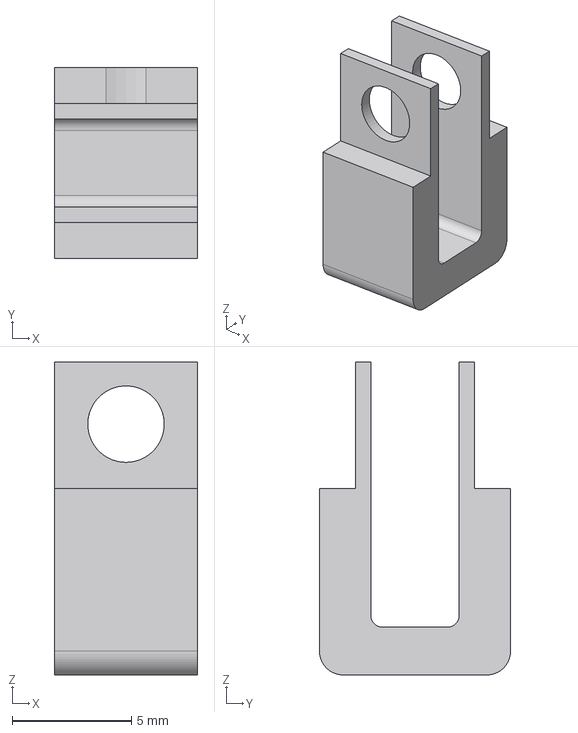
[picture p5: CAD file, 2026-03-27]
3d-files/top mount/v3.3.step
6.00 x 8.00 x 13.1 mm

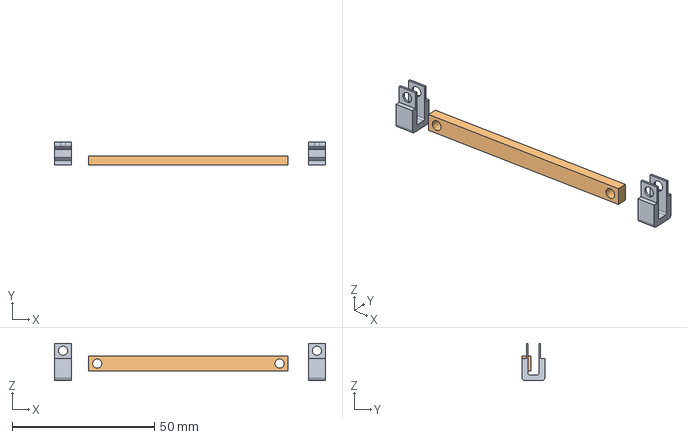
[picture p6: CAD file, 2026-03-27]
3d-files/top mount/v3.2 + bar v1.step
95.1 x 8.00 x 13.1 mm

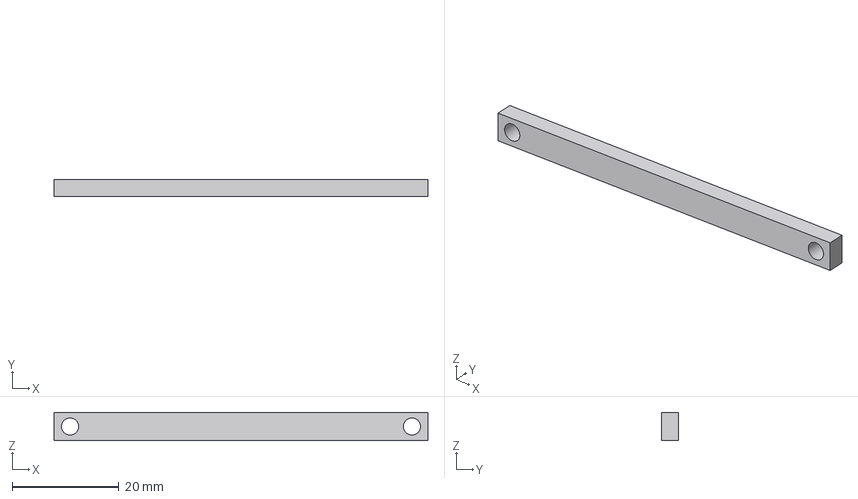
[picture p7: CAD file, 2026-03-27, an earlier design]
3d-files/archive/scene_cam/top_mount_step/v1 bar.step
70.0 x 3.20 x 5.30 mm

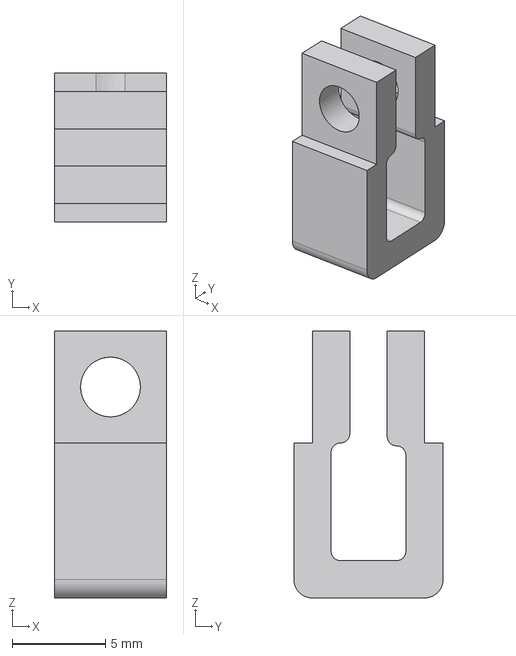
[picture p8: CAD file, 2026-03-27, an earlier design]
3d-files/archive/scene_cam/top_mount_step/v1.step
6.00 x 8.00 x 14.3 mm

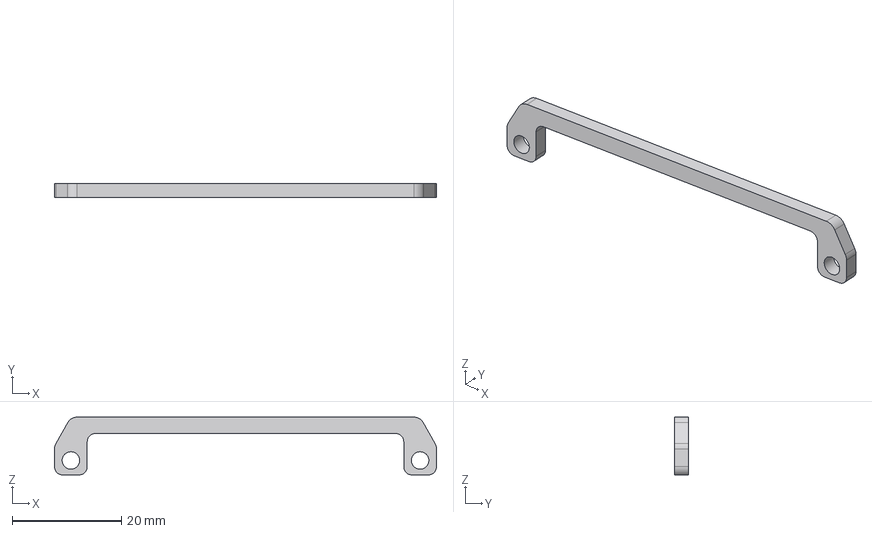
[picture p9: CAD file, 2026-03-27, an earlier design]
3d-files/archive/scene_cam/top_mount_step/v2 bar.step
70.0 x 2.50 x 10.6 mm

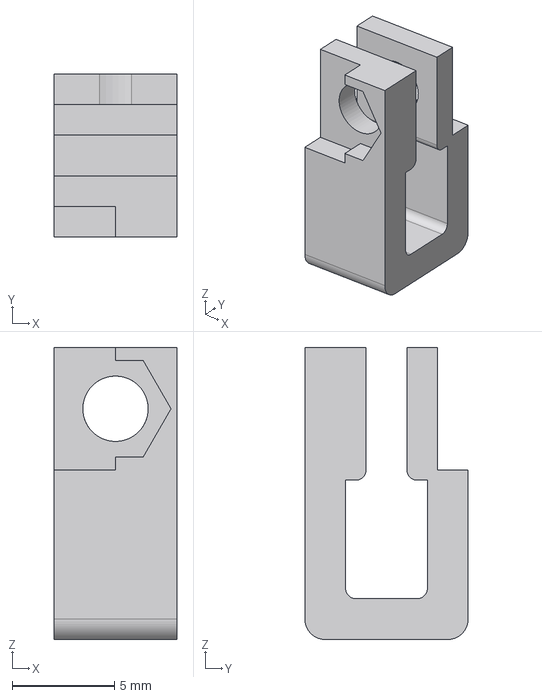
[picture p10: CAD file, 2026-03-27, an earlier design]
3d-files/archive/scene_cam/top_mount_step/v2.step
6.00 x 8.00 x 14.3 mm

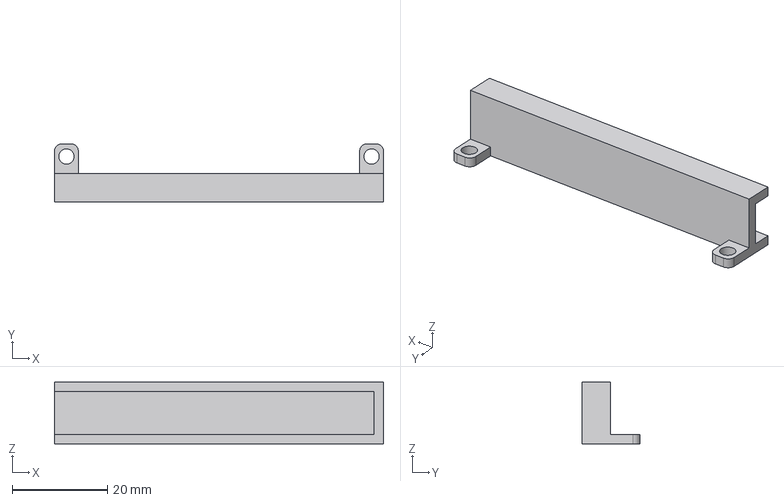
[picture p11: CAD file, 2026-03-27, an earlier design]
3d-files/top mount/v3 bar.step
69.0 x 12.2 x 13.0 mm

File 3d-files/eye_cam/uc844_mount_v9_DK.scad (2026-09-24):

// ============================================================================
// UC-844 Rev.B IR eye camera mount — v9
//
//   1) FRAME  - square frame + 4-corner PCB mount, lens/PCB drop in; PCB back stays open.

//   2) ARMS   - TWO separate brackets (one per side). Each: a clip-ear at the rod
//               (mating the real white clip) -> short body -> TODO: Find a way to attach to frame.
//               Stay out of the FOV; open center for the lens.

//   3) CLIPS  - the existing white clips (imported from the STEP as clip_ref.stl),
//               grip the rod to the sides; rotate([90,0,0]) seats them on the rod.
//
// Aim (from measurement estimates: pupil 27 mm above the rod, 19 mm behind the lens plane):
// lens tip ~30 mm from the pupil at ~38 deg up-tilt. Eye / rod / gaze-ray mocks +
// a 70 deg FOV cone confirm nothing blocks the view; echo() prints tip->pupil.
//
// Coords: origin = rod center; +X toward the face/eye; +Z up; rod along Y.
// ============================================================================

$fn = 60;
// "assembly" | "exploded" | "frame" | "arm" | "print"
show = "assembly";

// ---------------- PCB / frame ------------
pcb_size = 38; pcb_thickness = 1.6; hole_dia = 2.85;
hole_pitch = 34; insert_hole_dia = 3.6; insert_boss_dia = 7.0; corner_pad_margin = 1.0;
frame_wall = 3.0; register_depth = 1.0; register_clearance = 0.10;
lead_in_depth = max(pcb_thickness - register_depth, 0.6); lead_in_clearance = 0.30;
corner_relief_r = 0.6;
frame_outer = pcb_size + 2*frame_wall;   // 44
frame_height = register_depth + lead_in_depth; // == pcb_thickness, 1.6

// ---------------- eye / aim geometry (MEASURED) -------------------------
eye_depth = 19;   // pupil behind the lens plane (estimate)
eye_rise  = 27;   // pupil above the rod (estimate)
lens_len  = 15.86; // M12 lens length (Ø12 body / Ø14 front)
fov_deg   = 70;   // horizontal FOV of the lens
eye = [eye_depth, 0, eye_rise];

// ---------------- pose (frame placement) --------------------------------
// Frame bottom edge at local z=0, pocket +X; placed by rotate(-tilt) about the
// rod-parallel axis at (px,0,pz). Tuned so the lens tip is ~30 mm from the pupil.
tilt_angle = 38.8; // 38
px = -5; // -4.8;
pz = -20.5; // -19.6;

// lens seating face, frame-local X. Rear-mount: PCB sits behind the frame.
//   front drop-in : frame_height
//   rear, PCB front face on frame back : 0
//   rear, PCB back  face on frame back : -pcb_thickness
lens_base_x = 0;

// ---------------- clip / ear interface (from bottom mount/*.step) --------
// clip_pitch    = 18.7;   // Ø3.2 clip-screw spacing along the rod
clip_pitch = 22.5; // 39
clip_hole_dia = 3.2;
ear_screw_dia = 2.9;    // M2.5 clearance for the frame<->arm screws
ear_insert_dia = 3.6;   // M2.5 heat-set insert
ear_pitch     = 18.0;   // frame attach-ear spacing (Y)
ear_z_local   = 39;     // attach-ear height up the frame (local z)
arm_th        = 3;

// derived lens tip + report ----------------------------------------------
_a = lens_base_x + lens_len;
_b = frame_outer/2;
lens_tip = [ px + _a*cos(tilt_angle) - _b*sin(tilt_angle), 0,
             pz + _a*sin(tilt_angle) + _b*cos(tilt_angle) ];
tip_to_eye = norm(lens_tip - eye);
aim_deg    = atan2(eye[2]-lens_tip[2], eye[0]-lens_tip[0]);
echo(lens_tip = lens_tip, pupil = eye, tip_to_eye_mm = tip_to_eye,
     lens_axis_deg = tilt_angle, aim_needed_deg = aim_deg);

// ============================================================================
// FRAME MODULES
// ============================================================================
module oval_x_z(rx, rz) { scale([rx, rz, 1]) circle(r = 1); }
module pocket_profile(cl, rel) {
    union() { offset(delta=cl) square([pcb_size,pcb_size],center=true);
        for (x=[-1,1],y=[-1,1]) translate([x*pcb_size/2,y*pcb_size/2]) circle(r=rel); }
}
module pcb_pocket() {
    union() {
        linear_extrude(register_depth) pocket_profile(register_clearance, corner_relief_r);
        translate([0,0,register_depth]) linear_extrude(lead_in_depth+0.02)
            pocket_profile(lead_in_clearance, corner_relief_r+lead_in_clearance);
    }
}
module corner_pad_2d(xs,ys) {
    reach=hole_pitch/2-insert_boss_dia/2-corner_pad_margin; pad_span=frame_outer/2-reach;
    chamfer=pad_span*0.6;
    mirror([xs<0?1:0,0,0]) mirror([0,ys<0?1:0,0]) union() {
        difference() { translate([reach,reach]) square([pad_span,pad_span]);
            translate([reach,reach]) polygon([[0,0],[chamfer,0],[0,chamfer]]); }
        translate([hole_pitch/2,hole_pitch/2]) circle(d=insert_boss_dia);
    }
}
module corner_pad(xs,ys) {
    difference() { linear_extrude(frame_height) corner_pad_2d(xs,ys);
        translate([xs*hole_pitch/2,ys*hole_pitch/2,-0.5]) cylinder(h=frame_height+1,d=insert_hole_dia); }
}
module frame_body() {
    union() {
        difference() { linear_extrude(frame_height) square([frame_outer,frame_outer],center=true);
            pcb_pocket(); }
        for (x=[-1,1],y=[-1,1]) corner_pad(x,y);
    }
}

// ============================================================================
// PART 1 - FRAME PIECE 
// Local: pocket faces +X, back face at x=0, bottom edge at z=0, extends +Z.
// ============================================================================

function place_pt(p) = [ px + p[0]*cos(tilt_angle) - p[2]*sin(tilt_angle),
                         p[1],
                         pz + p[0]*sin(tilt_angle) + p[2]*cos(tilt_angle) ];
module frame_piece() {
    // frame standing: bottom edge -> z=0, pocket -> +X
    translate([0, 0, frame_outer/2]) rotate([0, 90, 0]) frame_body();

}

// ============================================================================
// PART 2 - TWO SEPARATE ARMS (one per side). Each: a clip-ear at the rod (mating
// the real white clip's Ø3.2 hole) -> short body -> ___
// ============================================================================
function clip_ear_pt(sy) = [clip_dx - 3.2, sy*clip_pitch/2, clip_dz];      // clip screw hole (vertical)

module one_arm(sy) {
    ce = clip_ear_pt(sy);   // ear pad center at clip screw hole
    
    // Calculate local Z height on frame corresponding to clip Z height
    local_z = (ce[2] - pz) / cos(tilt_angle);

    // Project straight horizontally from ce (-X towards frame)
    frame_x = px - local_z * sin(tilt_angle) - 5;
    
    frame_y = sy * frame_outer / 2;
    
    // frame_target = [frame_x, ce[1], ce[2]];
    frame_target = [frame_x, frame_y, ce[2]];
    
    // Total thickness and width of the arm extension
    arm_height = arm_th; // Matches your 5mm depth
    arm_width  = arm_th + 2; 

    difference() {
        union() {
            // Hull between two cubes that match the full 5mm height and width
            hull() {
                translate(ce) 
                    cube([arm_width, arm_width, arm_height], center = true);
                
                translate(frame_target) 
                    cube([arm_width, arm_width, arm_height], center = true);
            }
        }

        // Vertical clip screw clearance hole
        translate(ce) 
            cylinder(h = arm_height + 8, center = true, d = clip_hole_dia);
        
        // Trim everything past the frame's back surface plane
        place_frame() {
            translate([-100, -100, -100])
                cube([100, 200, 200]); 
        }
        
        // Trim outer Y overhang flush with frame walls
        if (sy > 0) {
            translate([-100, frame_outer/2, -100])
                cube([200, 100, 200]);
        } else {
            translate([-100, -100 - frame_outer/2, -100])
                cube([200, 100, 200]);
        }
        
    }
}

module arm() { for (sy = [-1, 1]) one_arm(sy); }   // assembly shows both

module frame_and_arms() {
    union() {
        frame_piece();
        
        // Transform the arms back into local frame coordinates
        rotate([0, tilt_angle, 0]) 
            translate([-px, 0, -pz]) 
                arm();
    }
}

// ============================================================================
// MOCKS  (eye + rod + gaze ray + lens FOV cone + eye FOV cone; not printed)
//         clips can be printed maybe...
// ============================================================================
module lens_mock() {
    translate([lens_base_x, 0, frame_outer/2]) rotate([0,90,0]) {
        color("DimGray") cylinder(h=lens_len, d=12);
        color("Black") translate([0,0,lens_len-3]) cylinder(h=3, d=14);
    }
}

// Rod is the bottom glasses frame
module rod_mock() { color("Silver") rotate([90,0,0]) linear_extrude(60,center=true) oval_x_z(2.5, 1.375); }
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

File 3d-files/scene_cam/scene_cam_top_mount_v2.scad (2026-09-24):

// ============================================================================
// scene_cam_top_mount_v2.scad
// Backing mount for the HUAQUE HQ-L103 SCENE camera + parametric rod clip.
//
// CHANGES FROM v1
//   * The imported white clip (clip_ref.stl) is replaced by a parametric
//     rod_clip() module, sized from rod_w / rod_t.  Same clip is used on the
//     UC-844 eye mount -> ONE clamp design for both cameras.
//   * The clip screw sits 5.40 mm from the rod center (identical to the eye
//     mount v8 interface: clip_dx - 3.2 = -5.4), so v8's arms are unchanged
//     apart from arm_th -> tab_t.
//   * The L-tab "ears" are gone.  At 5.40 mm the screw lands inside the plate
//     body, so the clip screws straight through the plate near its bottom
//     edge.  Stiffer than a cantilevered ear and a smaller overall envelope.
//   * plate_t is no longer free: it IS the tab thickness, derived from the
//     slot, so the plate is a snug fit in the clip.
//
// CLIP LOCAL FRAME (used by rod_clip):
//     origin = ROD CENTER
//     +X     = mouth direction (points out of the slot, toward the plate)
//      Y     = along the rod
//      Z     = slot normal (jaws stack in Z)
//
// PCB dimensions are from the manufacturer datasheet (62 x 9 x 1.0 mm board;
// two O2.2 holes 4.0 mm apart, 2.0 mm from the end).
// ============================================================================

/* =========================================================================
   VIEW  (pick one, then F5)
   ========================================================================= */
show = "assembly";   // "assembly" | "exploded" | "mount" | "clip" | "pcb"

$fn = 48;

// #########################################################################
// ## SHARED CLIP INTERFACE
// ## Keep byte-identical with the UC-844 eye mount, or better: move this
// ## block to clip_iface.scad and `include <clip_iface.scad>` from both.
// #########################################################################

/* ---- the rod (eyewear frame member the clip grips) ---------------------- */
rod_w        = 5.0;    // rod width, along the clip's X (mouth direction)
rod_t        = 3.5;    // rod thickness, along the clip's Z  <-- 2.75 on the
                       //   eye-camera rod; MEASURE both before printing
rod_clear_x  = 0.20;   // clearance behind the rod, in X

/* ---- fit ---------------------------------------------------------------- */
snap_fit     = 0.10;   // slot is rod_t - snap_fit -> interference snap.
                       //   0.10 in PETG is a firm push-on. Set 0 for a slip
                       //   fit, 0.20 if it still rotates on the rod.
tab_clear    = 0.10;   // slop between the slot and the plate/arm tab

/* ---- screw interface (DO NOT CHANGE - eye mount v8 depends on it) -------- */
screw_offset = 5.40;   // rod center -> screw axis, along +X
screw_dia    = 3.2;    // M3 clearance

/* ---- clip body ---------------------------------------------------------- */
jaw_t        = 2.00;   // wall above/below the slot (stock part was 0.65-1.15,
                       //   which is ~2 perimeters and splits under screw load)
clip_w       = 8.00;   // width along the rod (stock 6.0; wider = less roll)
back_wall    = 2.00;   // material behind the rod, at the closed end
nose_wall    = 1.20;   // material outboard of the screw hole
lead_in      = 1.00;   // mouth chamfer depth, for snapping over the rod
lead_in_z    = 0.45;   // mouth chamfer flare, per side
clip_r       = 1.20;   // outer corner radius

/* ---- derived: everything downstream keys off these ---------------------- */
slot_h    = rod_t - snap_fit;              // 3.40
tab_t     = slot_h - tab_clear;            // 3.30  <-- plate_t AND arm_th
clip_h    = slot_h + 2*jaw_t;              // 7.40
x_slot    = -(rod_w/2 + rod_clear_x);      // -2.70, slot closed end
x_back    = x_slot - back_wall;            // -4.70, clip back face
x_mouth   = screw_offset + screw_dia/2 + nose_wall;   // 8.20, clip front face

// #########################################################################
// ## END SHARED BLOCK
// #########################################################################


/* =========================================================================
   PARAMETRIC ROD CLIP
   Prints 2 per camera.  Orient it on the bed with the slot VERTICAL (lay it
   on a side face) so the jaws bend in-plane instead of peeling layers.
   Fastener: M3 SHCS + washer + nyloc nut.  The 2.0 mm jaw is too thin to
   pocket a nut or a heat-set insert; the nut goes on the outside.
   ========================================================================= */
module rod_clip() {
    difference() {
        // rounded-rectangle prism, swept along the rod (Y)
        hull()
            for (x = [x_back + clip_r, x_mouth - clip_r],
                 z = [-(clip_h/2 - clip_r), clip_h/2 - clip_r])
                translate([x, 0, z])
                    rotate([90, 0, 0])
                        cylinder(h = clip_w, r = clip_r, center = true);

        // the slot: rod pocket + tab channel, one continuous cut
        translate([x_slot, -clip_w/2 - 1, -slot_h/2])
            cube([x_mouth - x_slot + 2, clip_w + 2, slot_h]);

        // mouth chamfer, so the rod can be snapped in past the interference
        hull() {
            translate([x_mouth - lead_in, -clip_w/2 - 1, -slot_h/2])
                cube([0.01, clip_w + 2, slot_h]);
            translate([x_mouth + 1, -clip_w/2 - 1, -slot_h/2 - lead_in_z])
                cube([0.01, clip_w + 2, slot_h + 2*lead_in_z]);
        }

        // clip screw
        translate([screw_offset, 0, -clip_h])
            cylinder(h = 2*clip_h, d = screw_dia);
    }
}

// visual stand-in for the rod (not printed)
module rod_mock(len = 90) {
    color("Silver")
        translate([0, 0, 0])
            rotate([90, 0, 0])
                linear_extrude(len, center = true)
                    offset(r = min(rod_w, rod_t)/2 - 0.01)
                        square([rod_w - min(rod_w,rod_t) + 0.02,
                                rod_t - min(rod_w,rod_t) + 0.02], center = true);
}

/* =========================================================================
   PCB  (from datasheet - measured)
   ========================================================================= */
pcb_len       = 62.0;   // board length
pcb_width     = 9.0;    // board width
board_thick   = 1.0;    // bare PCB thickness
lens_protrude = 4.68;   // how far the camera module stands off the front face

// Two plated mounting holes at ONE end (the camera is 32.5 mm from this end):
hole_dia      = 2.2;
hole_spacing  = 4.0;
hole_from_end = 2.0;

// Third mounting hole near the connector end -> 3-point clamp:
third_hole      = true;
third_from_conn = 10.2;
third_y_offset  = -2.0;

/* =========================================================================
   BAR / CLIP PLACEMENT
   ========================================================================= */
clip_hole_pitch = 64.0;  // free parameter - the clips slide along the rod.
                         //   Need NOT match the eye mount's 22.5.
clip_end_margin = 4.5;   // half the clip width + a little
bar_len         = clip_hole_pitch + 2*clip_end_margin;   // -> 73
edge_gap        = 0.50;  // gap between the rod and the plate's bottom edge

/* =========================================================================
   PLATE + RETENTION  (tunable)
   ========================================================================= */
plate_t        = tab_t;  // DERIVED - must equal the clip's tab thickness
frame_far      = 2.5;    // border above the PCB (away from the rod)
pocket_clear   = 0.30;
use_insert     = false;  // false = M2 self-tap into plastic; true = heat-set
screw_pilot_dia= 1.6;
insert_dia     = 3.2;
win_end_inset  = 8.0;
win_edge_inset = 2.0;
conn_relief_w  = 7.0;
lip_reach      = 1.0;
lip_h          = 1.0;
// lip width is DERIVED: the lips only ever hold down the strip of board left
// either side of the cable relief, so they span relief edge -> PCB edge.  A
// fixed 3 mm lip overhung the frame and fouled the clip's upper jaw.
lip_w          = (pcb_width - conn_relief_w)/2;   // -> 1.0

/* =========================================================================
   DERIVED
   ========================================================================= */
// rod center and clip screw, in plate coordinates (plate bottom edge at y=0)
rod_y       = -(rod_w/2 + rod_clear_x + edge_gap);   // -3.20
clip_screw_y= rod_y + screw_offset;                  // +2.20
clip_reach_y= rod_y + x_mouth;                       // +5.00, clip's far face

// bottom border must clear the screw hole AND the clip body
frame_rod = max(frame_far,
                clip_screw_y + screw_dia/2 + 1.2,    // wall around the hole
                clip_reach_y + 0.5);                 // clip must not foul the PCB
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

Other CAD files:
3d-files/top mount/v3.2.step
3d-files/top mount/v3.step
3d-files/top mount/v3.1.step
3d-files/archive/scene_cam/top_mount_step/v3.1.step
3d-files/archive/eye_cam/uc844_mount_v2_dipped_spine.scad
3d-files/archive/eye_cam/uc844_mount_v6_arm.scad
3d-files/archive/eye_cam/glasses_rod_adapter.scad
3d-files/archive/eye_cam/uc844_mount_v1.scad
3d-files/archive/eye_cam/uc844_mount_v3_rod_clamp.scad
3d-files/archive/eye_cam/uc844_mount_v4_pivot.scad
3d-files/archive/eye_cam/uc844_mount_v5_centered.scad
3d-files/archive/eye_cam/uc844_mount_v7_two_arm.scad
3d-files/archive/eye_cam/uc844_mount_v8_DK.scad
3d-files/archive/scene_cam/scene_cam_top_mount_v1.scad
3d-files/archive/scene_cam/top_mount_step/v3.2.step
3d-files/archive/scene_cam/top_mount_step/v3.step

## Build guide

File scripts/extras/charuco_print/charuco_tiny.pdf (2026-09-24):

50 mm — verify with ruler before use TINY sq=5mm mk=3.6mm 30x24 IDs 500-859 DICT_5X5_1000 100%/Actual size only

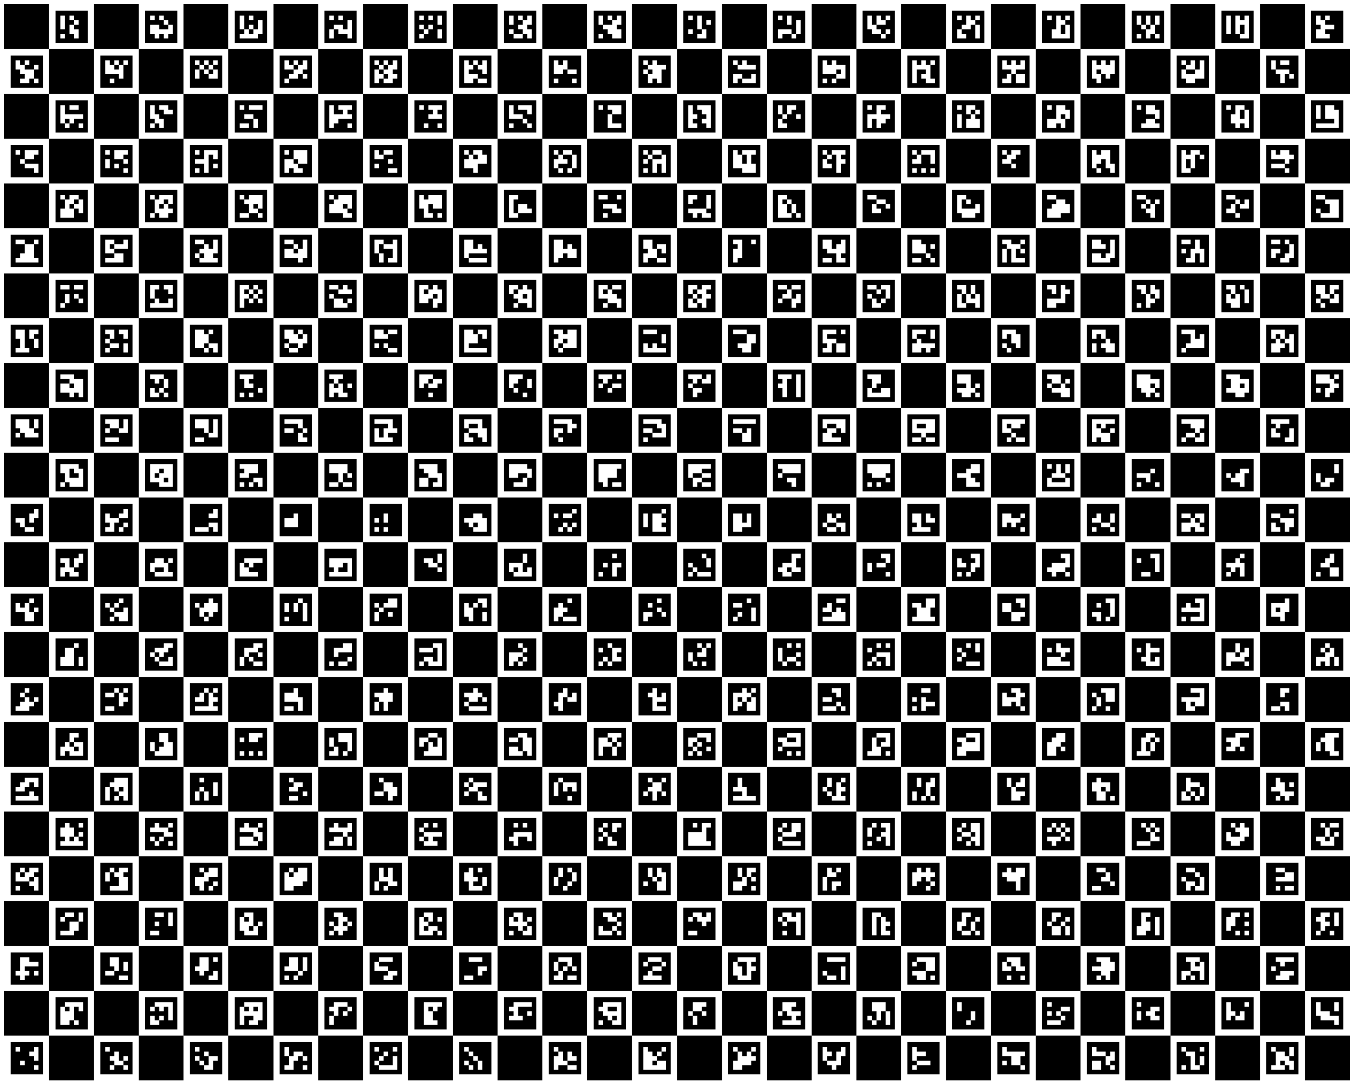
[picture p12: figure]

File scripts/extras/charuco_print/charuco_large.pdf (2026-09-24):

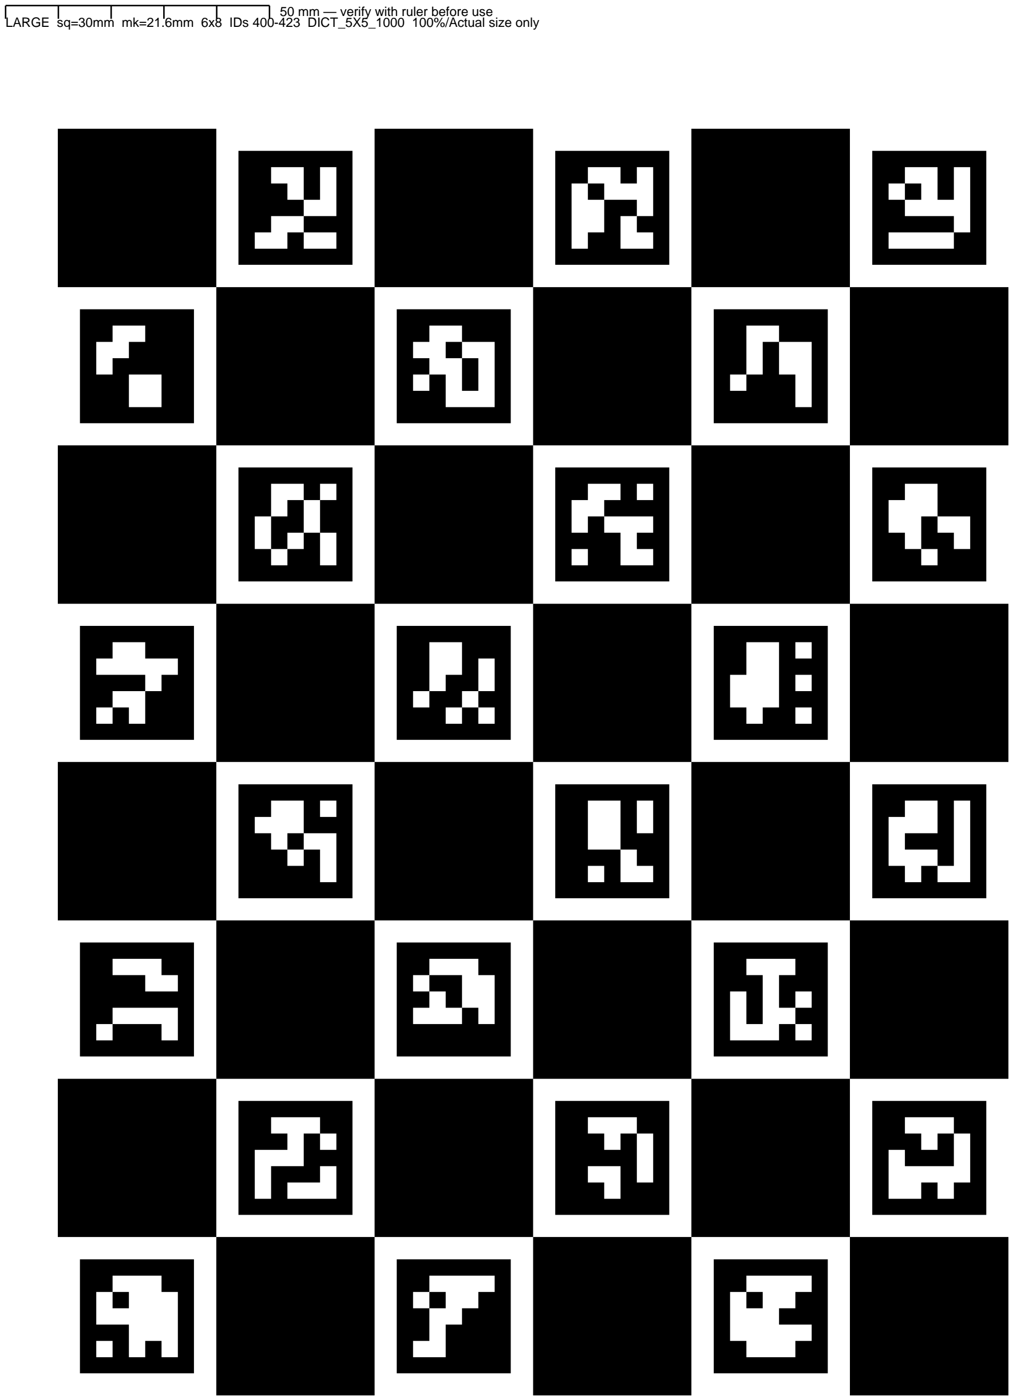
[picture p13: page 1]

50 mm — verify with ruler before use LARGE sq=30mm mk=21.6mm 6x8 IDs 400-423 DICT_5X5_1000 100%/Actual size only

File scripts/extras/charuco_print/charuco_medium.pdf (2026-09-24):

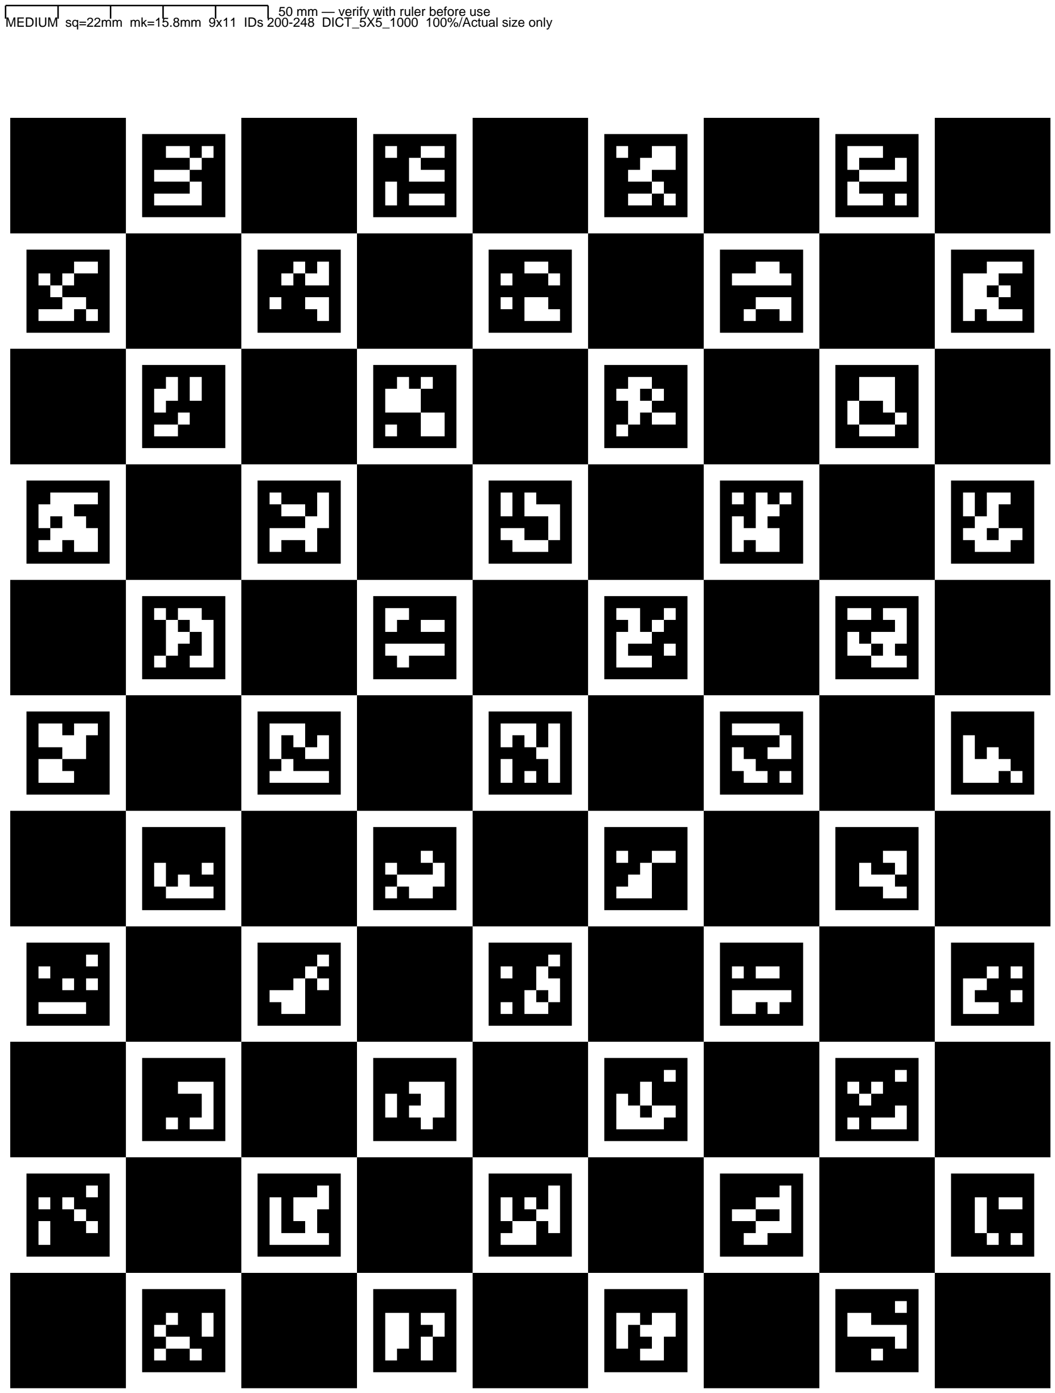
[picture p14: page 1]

50 mm — verify with ruler before use MEDIUM sq=22mm mk=15.8mm 9x11 IDs 200-248 DICT_5X5_1000 100%/Actual size only

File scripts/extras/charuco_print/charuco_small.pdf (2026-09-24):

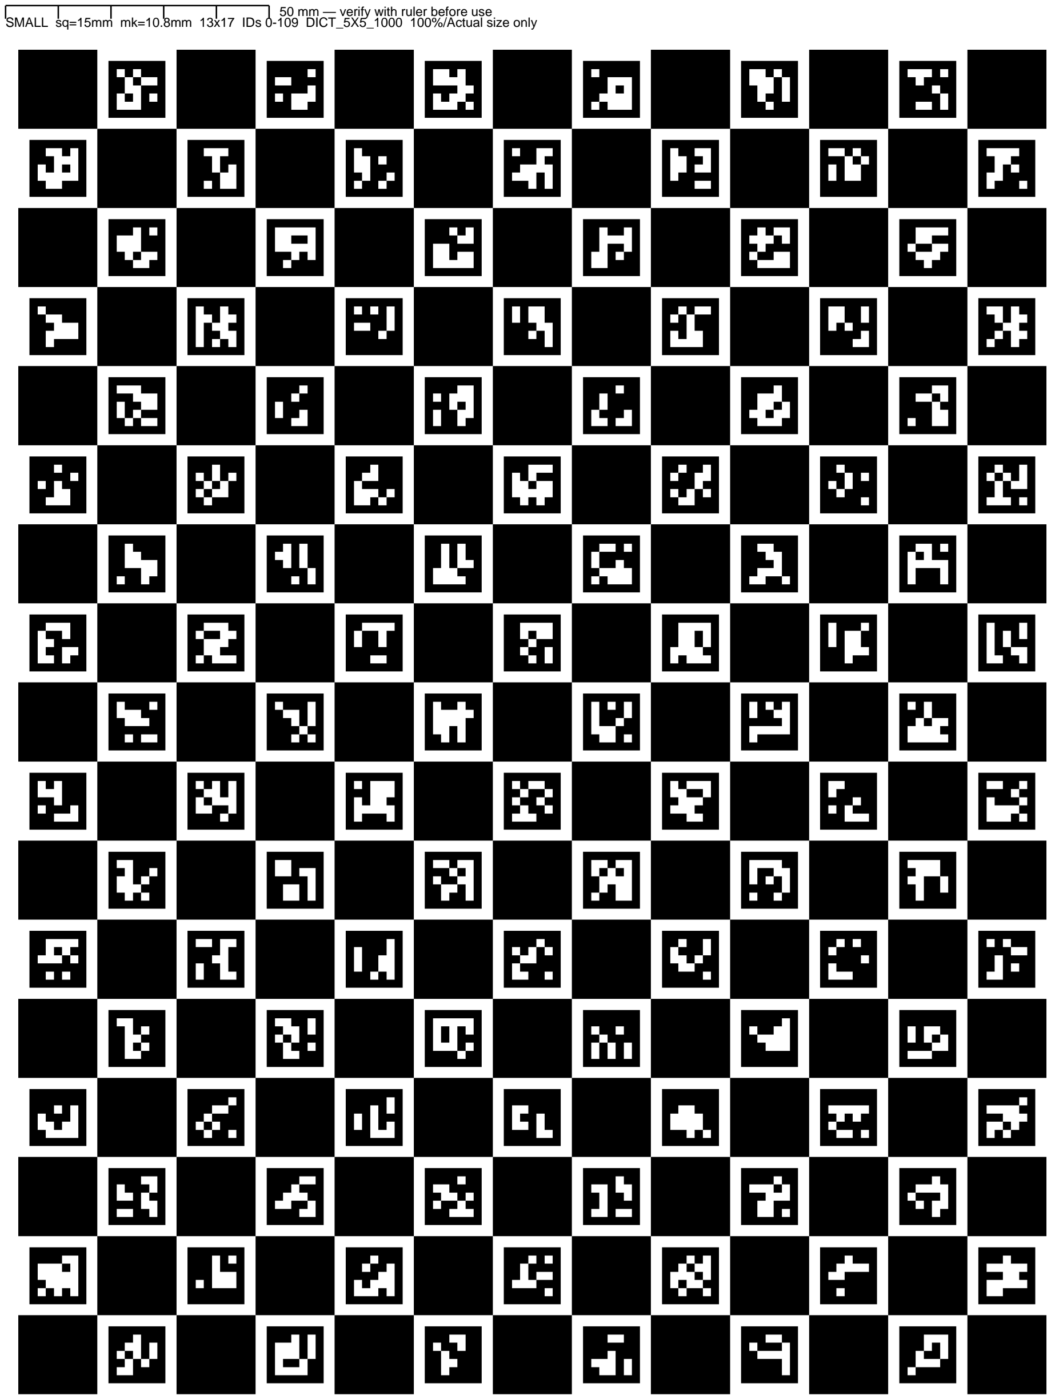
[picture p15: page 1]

50 mm — verify with ruler before use SMALL sq=15mm mk=10.8mm 13x17 IDs 0-109 DICT_5X5_1000 100%/Actual size only

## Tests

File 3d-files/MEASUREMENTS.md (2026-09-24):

# Hardware Measurements & Constraints

Reference for the 3D-printed mount / CAD design work. Update as new measurements
arrive. Covers two separate projects: the **eye camera** mount and the **scene
camera** top mount.

---

## Eye camera — PCB (UC-844 Rev.B)

- **Board:** 38.0 × 38.0 mm, thickness 1.6 mm. Single-sided (components on the front).
- **Mounting holes:** 4-corner pattern, compatible with **both 34 × 34 mm and
  28 × 28 mm** pitch (two hole sets). Corner hole radii ≈ R1.30 / R1.40 mm
  (≈ Ø2.6 / Ø2.8). Mount design (v3/v4) uses Ø2.85 clearance at 34 mm pitch with
  M2.5 heat-set inserts.
- **Reference outlines on the datasheet:** 38 / 34 / 28 mm nested squares.
- **Imager / sensor:** centered on the board (19 mm from edges to center).
- **Lens:** centered on the board.
- **USB connector** (4-pin: VCC, DM, DP, GND): on the **back** of the PCB,
  **bottom-left**. Approx ~7.56 mm wide × ~3.81 mm tall, ~3.47 mm up from the bottom
  edge, ~8.24 mm in from the left edge.
  → **Keep the PCB back open** (connector access + heat dissipation).

## Eye camera — Lens (M12)

- **Mount:** M12 × P0.5 mm (threaded → refocusable in the holder).
- **EFL:** 2.8 mm. **FOV:** 70° (H). **Distortion:** < 1%.
- **Optical format:** 1/4".
- **Mechanical:** overall length 15.86 mm; front Ø14 ± 0.05; body Ø12; segment lengths
  4.3 / 8.9 / 13.2 mm; aperture ≈ Ø9.
- **Video:** 720p.
- **Focus:** datasheet "Macro Focus Range 100 cm" is a **typo** — bench-tested and it
  focuses **sharply down to ~1 cm**. No lens swap needed; focus does **not** constrain
  how close the camera can sit. (Working distance is limited by FOV/framing and face
  clearance, not focus.)

## Eye camera — IR illumination

- **One IR LED**, hand-soldered, mounted a bit above the lens (off-axis). Replaced the
  older eye cam's two side-by-side LEDs.
- Off-axis, so the pupil images dark (no retroreflection / bright-pupil effect), with a
  single corneal glint.

## Eye camera — aim geometry

- **Target lens-tip-to-eye distance:** ~44–51 mm (1.75–2″). Can go closer if desired
  (focus allows down to ~1 cm); limited by FOV/framing and face clearance.
- **Eyeball depth:** ~19 mm (0.75″) behind the glasses lens plane (the vertical plane
  through the top and bottom rims).
- **Pupil height:** ~27 mm (2.7 cm) above the bottom rod.
- **Rod spacing:** ~46 mm (4.6 cm) between the bottom and top rods (context / the
  lens-plane height).
- **Preferred tilt:** ~60° for the internal eye cam (design notes in `README.md`).
- **Placement intent:** lens just **below** the eye (out of the sightline), angled
  **up** at the pupil, as close as practical.

## Eye camera — glasses rod (clamp target)

- **Cross-section:** ~2.5–3 mm tall (vertical, Z), ~5 mm deep (fore-aft, X), rounded
  (not a true cylinder).
- **Usable horizontal length for the clamp:** ~1 inch (~25 mm).
  → mount must be **compact and centered**; no side-hanging hardware / across-face
  overhang.

---

## Scene camera — PCB (HUAQUE HQ-L103) — separate "top mount" project

- **Board:** 62 × 9 × 1.0 mm (bare PCB). Lens Ø ~5.68 mm, protrudes ~4.68 mm off the
  front face.
- **Mounting holes:** Ø2.2 drilled (Ø3.2 pad).
  - Two at the **camera end**: 4.0 mm apart (± 2.0 mm off the width centerline),
    2.0 mm from the end edge.
  - Third near the **connector end**: Ø2.2, ~10.2 mm from the connector-end edge,
    ~2.0 mm off the centerline.
- **Feature positions (from the mounting-hole end):** camera 32.5 mm, LED 12.5 mm.
- **Rod clips:** reuses the existing white rod clips — Ø3.2 clip holes at **64 mm
  pitch** (taken from the current bar's STEP file).
- File: `3d-files/scene_cam_top_mount_v1.scad`.

---

## Mount design constraints (derived, eye camera)

- Reuse the v3/v4 **square frame + 4-corner PCB screw mount unchanged**.
- Keep the **PCB back open** (USB connector + heat).
- **Centered / compact** within the ~1 inch of usable rod; no across-face overhang.
- **Tilt adjustable** (friction pivot, axis parallel to the rod) + **standoff
  adjustable** (slot); final aim done on the live camera feed.
- Mount is **lens-agnostic** (holds the PCB; the lens protrudes through the open
  window), so any M12 lens change needs no design change.

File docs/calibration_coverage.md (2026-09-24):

# Calibration Coverage and Eccentricity Validation

Why the tracker is accurate when you look near the center of your view and worse
when you look off to the side — how we *measure* that gap, and (in
[`multipose_calibration.md`](multipose_calibration.md)) how we close it.

This doc assumes you've read [`polynomial_gaze_mapping.md`](polynomial_gaze_mapping.md),
which explains the pupil→scene polynomial and the ArUco homography. Here we care
about *where in the user's field of view the fit is trustworthy*, not the fit math.

## The current calibration setup, in one paragraph

The user looks at a grid of red dots drawn on a monitor. Four ArUco markers at the
screen corners let us compute a per-frame **screen→scene homography**, which turns
each dot's screen pixel into its location in the scene-camera image. For each dot we
record one `(pupil_pixel, scene_pixel)` pair — pupil center from the eye camera,
scene pixel from the homography. After the grid we least-squares-fit a degree-2 or
degree-3 bivariate polynomial `pupil → scene` (`scripts/eyetracker/gaze/polynomial.py`).
Two grids ship today: quick (`c`, 3×3, degree 2) and detailed (`d`, 5×4, degree 3,
with worst-point recapture). Grid sizes, margins, and degrees live in
`scripts/eyetracker/config.py` under `CALIB_QUICK_*` / `CALIB_DETAILED_*`.

### What it solves

- **Per-subject, per-rig geometry without modeling it.** The eye is a sphere viewed
  off-axis by the eye camera; the exact pupil→gaze relationship depends on eye shape,
  camera placement, and how the headset sits. The polynomial learns that relationship
  empirically from a dozen-ish points, so we never have to measure kappa, eye radius,
  or camera extrinsics to get a usable gaze estimate.
- **Head-pose invariance at runtime.** The homography absorbs *where the screen is*
  during calibration, so the learned polynomial is purely `pupil → scene-cam`, a
  property of the headset rig. Move your whole body around the room afterward and the
  polynomial still holds (see the "Mental model" section of the polynomial doc).
- **Noise averaging.** More fixations than coefficients (e.g. 20 points for 10
  degree-3 coefficients) means `lstsq` averages out pupil jitter and marker shake
  instead of memorizing it.

### What it does *not* solve — the coverage problem

Every calibration dot lives on the monitor, and the monitor occupies a small patch
near the **center** of the scene camera's view. So:

- The **labels** (scene pixels) cluster in a small central region.
- The **inputs** (pupil positions) only span the eye rotations needed to scan that
  small region — a narrow band of pupil pixels.

A polynomial is reliable *inside* the cloud of data it was fit on and unreliable
outside it. When you later look somewhere the calibration never sampled — past the
edge of where the screen was — the model **extrapolates**, and a degree-3 polynomial's
cubic terms diverge fast. That is the edge degradation: it is a property of *coverage*,
not of slippage or hardware.

> A common misread is "just spread the dots wider on the screen." On a normal monitor
> that barely widens the *pupil* range, because the maximum eye rotation is capped at
> roughly half the screen's angular width. Widening coverage means getting the eye to
> rotate further — which is what [multi-pose calibration](multipose_calibration.md)
> does by moving the head, not the dots.

## Why measure it as *eccentricity*

To know whether a fit is trustworthy "in the center" vs "at the edge," we need a single
number for "how far off-axis is the user looking." That number is **(optical) eccentricity**: the
angular distance of a gaze point from the scene camera's optical axis (its principal
point).

For a point at scene pixel `(u, v)` with camera intrinsics `K`:

```
r        = hypot(u - cx, v - cy)          # pixels from the principal point
ecc_deg  = degrees(atan(r / fx))          # angular distance from the optical axis
```

where `fx = K[0,0]` and `(cx, cy) = (K[0,2], K[1,2])`. See `_eccentricity_deg` in
`scripts/extras/measure_gaze_accuracy.py`.

Eccentricity is the right axis to bin by, for three reasons:

1. **It's the variable the polynomial extrapolates along.** Error grows with distance
   from the calibrated cloud, and that cloud is centered on the optical axis. Binning by
   eccentricity exposes exactly the trend that a single average hides.
2. **It's resolution- and lens-independent.** "30 px of error" means different things
   at 720p vs 4K, or with a wide vs narrow lens. Degrees of visual angle are comparable
   across rigs and are the unit accuracy is quoted in (Pupil Labs Neon is ~0.5–1°).
3. **It maps onto how the eye actually works.** The scene camera points roughly along
   head-forward, so scene-frame eccentricity ≈ the eye's rotation away from
   head-forward — i.e. where in the **oculomotor range** the user is. People turn their
   *head* to look far off-axis, so in practice gaze rarely exceeds the comfortable
   oculomotor range (~±20–25°); that range is exactly what we want covered and measured.

   (This is an approximation: it assumes the scene-cam optical axis ≈ head-forward and
   ignores eye↔scene-camera parallax and target depth. Good enough to rank center vs
   edge; see "What could be improved.")

## The validation tooling

A single average error over the calibration points is misleading twice over: the points
are clustered in the center, *and* leave-one-out error only tells you about regions you
calibrated. Two pieces fix this.

### 1. Held-out capture — the `v` key

`v` runs the same grid as the detailed calibration but in **collect-only** mode: it
fits nothing and never touches the live `calibration.json` or the in-memory mapper
(`CalibrationRoutine(fit_on_finish=False)` in `scripts/eyetracker/calibration/routine.py`).
It saves a normal `data/calibration/session_<ts>/` (labels.csv + metadata.json) tagged
`phase: validation`, with no fit.

The point: capture a `v` set **at a steep head angle** so its gaze points land at high
eccentricity — out where the calibration never sampled. That gives you ground-truth
pairs the fit has never seen, in the region you most want to test.

### 2. Eccentricity-binned measurement

`python -m scripts.extras.measure_gaze_accuracy [--val <validation session dir>]` refits the
polynomial from a saved calibration and reports error binned by eccentricity:

- **In-sample**, using **leave-one-out** error (refit without each point, predict it).
  LOO is used here because these points *were* in the fit; training residuals would
  flatter the fit by measuring how well it memorized its own labels.
- **Held-out**, using the **plain full-data fit** to predict each `--val` point. No LOO
  needed — the validation points were never in the fit, so there's no leakage.
- A **coverage report**: the pupil-pixel range and the eccentricity histogram of the
  calibration labels, so under-coverage is visible before you even look at error.

### Reading the output

A sample run on a head-on detailed calibration (no `--val` yet):

```
Coverage (fit set):
  pupil x:   269.0 ..   377.0 px   y:   211.0 ..   267.0 px
  gaze eccentricity: 2.0° .. 24.5°   [0-5°:1  5-10°:5  10-15°:6  15-20°:7  >20°:1]

In-sample LOO error by eccentricity:
      band    n      mean   mean°       max    max°
      0-5°    1     9.8px   0.30°     9.8px   0.30°
     5-10°    5    11.3px   0.34°    17.6px   0.53°
    10-15°    6    18.5px   0.56°    32.7px   0.99°
    15-20°    7    23.9px   0.72°    73.1px   2.21°
      >20°    1    35.8px   1.08°    35.8px   1.08°
   overall   20    19.0px   0.58°    73.1px   2.21°
```

Two things to notice. First, the **pupil range is tiny** (≈108 px wide, ≈56 px tall) —
the eye barely moved during calibration. Second, error **climbs monotonically with
eccentricity** (0.30° at center → 0.72° by 15–20°), even *within* the calibrated region.
Add a wide-angle `--val` set and the outer bins blow up further, because that's pure
extrapolation. That growth curve, not the single "overall" number, is the thing to drive
down.

## What could be improved

- **Eccentricity is an approximation to true gaze angle.** It's measured in the scene-cam
  frame relative to the principal point, assuming the scene cam looks along head-forward
  and ignoring eye↔scene parallax and target depth. With eye↔scene extrinsics from the calibration jig (see
  `docs/data_collection.md`) and a depth estimate, this could become a true
  eye-relative visual angle.
- **The polynomial itself is the ceiling.** Widening coverage fixes catastrophic
  extrapolation but a global low-degree polynomial has fixed capacity — fitting a wider,
  more nonlinear domain can trade a little center accuracy for the edges. The real fix is
  higher-capacity or local models, ultimately the planned image-to-gaze approach, which
  this richer, eccentricity-spanning data collection is meant to feed.
- **Validation labels still ride on the ArUco homography**, so a steep-angle `v` set is
  only as good as marker detection at that angle (all four corners must stay in frame).

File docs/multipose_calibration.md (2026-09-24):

# Multi-Pose Calibration

How we widen the calibrated region of the field of view so gaze stays accurate when
the user looks off-center — the fix for the coverage problem described in
[`calibration_coverage.md`](calibration_coverage.md).

## The problem, recapped

A normal head-on calibration only samples a narrow band of eye rotations: every dot is
on a monitor that fills a small patch near the center of the scene camera's view. The
pupil→scene polynomial is then trustworthy only inside that small central cloud and
extrapolates badly outside it. We want to extend the cloud toward the full comfortable
oculomotor range (~±20–25°) without buying a bigger screen.

## The mechanism: move the head, not the dots

The key fact (same one that makes the polynomial head-pose invariant at runtime) is that
the scene camera is **head-mounted**, so the pupil→scene mapping is *head-relative*.

Rotate your **head** ~30° away from the screen but keep fixating the dots, and two things
happen at once:

- The screen now lands near the **edge** of the scene-camera frame, so the homography
  places the labels at high eccentricity.
- Your eye must rotate ~30° to keep fixating, so the **pupil** moves into a position a
  head-on calibration never reaches.

Both the input cloud (pupil) and the output cloud (scene pixels) extend together. The
control variable is **head orientation relative to the target**, not screen tilt — and
it reaches eye rotations that are simply unavailable when the screen sits dead-center
(where max eye rotation ≈ half the screen's angular width).

### Why discrete static poses, not continuous motion

Capture must happen while the head is **still**. The per-fixation gate
(`SampleCollector` in `scripts/eyetracker/calibration/collector.py`) rejects a fixation
if the scene label drifts more than `CALIB_SCENE_STD_THRESH` px ("Head may have moved").
That gate is correct and we keep it. So the routine is a sequence of **static poses**:
reposition the head → hold still → run a grid → reposition → next pose. Continuous
"look around while moving" would both trip the gate and desync the eye/scene cameras
(the pupil frame and the homography label would come from slightly different instants),
injecting label noise that scales with motion speed.

Do all poses in **one session without removing or adjusting the headset**, so headset
slippage doesn't drift between poses — every pose then samples the same pupil→scene map.

## The routine

Press **`m`** to start. Multi-pose reuses the existing grid + homography + collector; the
only new behavior is a loop over poses that accumulates into a single fit
(`CalibrationRoutine` with `num_poses > 1`, in `scripts/eyetracker/calibration/routine.py`).

Flow:

1. **Pose 1** is captured exactly like a normal grid. The overlay shows `Pose 1/5` and
   per-pose guidance.
2. When the grid completes and poses remain, the routine enters a **pose break**
   (`_begin_pose_break`): it stops collecting and the overlay shows the next pose's
   instruction (e.g. "turn your head LEFT") plus the live `aruco: N/4 markers visible`
   readout. Captured points are **not** cleared.
3. The user repositions and presses **`c`** to start the next pose (`begin_next_pose`):
   the same grid is re-armed, `current_idx` resets, but the accumulated buffers carry
   over.
4. After the **final** pose, all `(pupil, scene)` pairs across every pose feed one
   `lstsq` fit (the existing `_finish` path).

So 3 poses × a 12-point grid → 36 points (60 with all 5 poses) feeding one degree-3 fit, spanning a much wider
slice of the oculomotor range than 20 head-on points.

Two-pass **recapture is disabled** in multi-pose (`recapture_worst_n = 0`). Recapture
re-prompts the worst points, but "the worst point" came from a specific head pose; redoing
it at whatever pose the user happens to be in would be ambiguous.

### Configuration

In `scripts/eyetracker/config.py`:

| Constant | Meaning |
| --- | --- |
| `CALIB_POSES` | number of head poses (default 3: head-on, left, right; up to 5 adds down, up) |
| `CALIB_MULTIPOSE_ROWS` / `_COLS` / `_MARGIN` | grid per pose (default 4×3, margin 180) |
| `CALIB_MULTIPOSE_DEGREE` | polynomial degree (default 3 — plenty of points to support it) |
| `CALIB_POSE_GUIDANCE` | per-pose instruction strings shown on the overlay |

`next_pose_guidance()` falls back to a generic prompt if you raise `CALIB_POSES` beyond
the number of guidance strings, so the two can be tuned independently.

### Practical limits

- **ArUco visibility bounds the pose.** At steep angles the screen rotates toward the
  edge of the scene frame and a corner marker can drop out. The existing "not all 4
  markers visible" guard simply won't capture until all four are back — the `aruco: N/4`
  readout tells the user when a pose is too extreme.
- **Oculomotor comfort bounds it too.** Beyond ~±25° of eye rotation fixation gets
  uncomfortable and unstable; that's also roughly where real users start turning their
  head instead, so it's a sensible ceiling rather than a limitation to fight.

## What it improves (and what it can't)

- **Improves:** the *usable* field of view. Outer-eccentricity error should drop sharply
  because those regions are now interpolation instead of extrapolation. It also enriches
  the per-session image dataset (eye + scene frames are saved per sample regardless), so
  the future image-to-gaze model gets training data spanning the full oculomotor range —
  the main motivation.
- **Can't:** raise the polynomial's *center* ceiling. A global degree-3 fit has fixed
  capacity; spreading data over a wider, more nonlinear domain may trade a little
  peak-center accuracy for the edges. Lifting the ceiling needs a higher-capacity or
  local model — the planned image-to-gaze pivot.

## Verifying it worked

Multi-pose is exactly the kind of change that needs the
[eccentricity validation tooling](calibration_coverage.md#the-validation-tooling) to
confirm — "feels better" isn't measurable. End-to-end:

1. Capture a held-out wide-angle set once with `v` (steep head angle). Keep this
   validation session fixed so it's a fair yardstick across runs.
2. Measure your **current head-on** calibration against it:
   `python -m scripts.extras.measure_gaze_accuracy --val data/calibration/session_<validation ts>`
   — expect large error in the outer eccentricity bins (the gap).
3. Recalibrate with `m` across all poses (don't touch the headset), confirming LOO stays
   under the usable threshold (`0.04 × scene_width`).
4. Re-measure against the same `--val` set. The outer bins should drop substantially.
   Watch the center bin too, to quantify any trade-off.

## Future direction

Multi-pose reuses the screen + ArUco rig, so coverage is still bounded by screen size and
marker visibility. A more scalable rig for the model dataset is **world-fixed fiducials**
— a printed ArUco wall or poster — letting targets span the full scene FOV independently
of any screen, and dovetailing with the extrinsics jig. That's deliberately out
of scope here; multi-pose is the no-new-hardware step.

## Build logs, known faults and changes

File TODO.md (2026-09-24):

# TODO

Running backlog of open work. Put the branch/PR next to an item while it's in
flight; check it off when the work is done on its branch, and delete it once
that merges (git history keeps it). Move any finding worth keeping (a
measurement, a gotcha) into the relevant doc first. Detailed per-feature plans
get their own `TODO_<topic>.md` (e.g. `TODO_multipose_coverage.md`).

Rig: Jetson Orin (JetPack 6, Ubuntu 22.04) + Philips 221V8LB @ 1920x1080 100 Hz.
Eye cam: Arducam OV9281 (`0x0c45:0x6366`). Scene cam: `0x0bda:0xd565`.
What we've learned so far: `docs/findings.md`.

## Next up

In order; details in the items below. Update this list at every milestone.

1. Test and merge `timestamping` (`git pull` on the Jetson first)
2. Pin the eye cam mode (Capture architecture)
3. On the rig: undistorted-homography check, then merge `use-intrinsics-for-homography`
4. Print and paste the jig boards; run eye intrinsics + extrinsics (Accuracy)
5. Record the rig calibration in session `metadata.json`, then polish data collection

Steps 3 and 4 can share one session at the rig.

## Linux port

- [ ] Check the scene exposure hotkeys and `metadata.json` from a real session

## Capture architecture

- [ ] Stamp each frame on arrival in the grabber thread (feeds timestamping below).
      Done on `timestamping`.
- [ ] App loop still blocks on the 30 fps scene read, so the eye is processed
      at ~30 Hz, not ~100. Decouple so every eye frame is processed.
- [ ] ArUco on full 1080p is ~45 ms/frame, so the loop drops to ~14 Hz during
      calibration. Try detecting on a downscaled frame and rescaling corners.
- [ ] Jetson power mode: currently 15W; try `sudo nvpmodel -m 2` (MAXN_SUPER)
- [ ] Main loop consumes the latest eye frame; scene frames matched by timestamp
- [ ] Pin the eye cam mode: request it in `_eye_cam_settings()` (today it's the
      driver default, so the cropped 640x480 frame's geometry can change). On the
      rig, compare the field of view at 640x480 vs 1280x800 (full sensor or a
      crop?), and consider 120 fps (640x480 MJPG measured 121 fps alongside the
      1080p scene on the shared USB 2 hub; `HIGH_FPS_MODE`).
- [ ] Then use the measured eye focal length (fx in `eye_intrinsics.json`) for
      pye3d and `metadata.json` instead of `EYE_CAM_FOV_DEG` (80°, the old Sonix
      lens)

## Timestamping + sync

- [ ] Hardware / driver frame timestamps for both cams (V4L2 buffer timestamps,
      UVC PTS/SCR), logged per frame
- [ ] Log calibration-dot onset times on the host clock (flip-accurate at 100 Hz)
- [ ] Clock offset / drift / round-trip estimation between camera clocks and
      the host: LSL, or our own NTP-style exchange
- [ ] Offline tool: align eye + scene + stimulus streams from logged timestamps

## Accuracy: depth / parallax + headset slip

Remaining error is physical (depth parallax + headset slip), not the
calibration code: see the 2026-09-23 entry in `docs/findings.md`.

- [ ] Scene-cam intrinsics (`scripts/extras/calibrate_scene_intrinsics.py`);
      also unlocks degree-based accuracy in `measure_gaze_accuracy.py`
- [ ] Per-sample ArUco data in the session dataset (store raw, derive later):
      - `aruco.csv` per session, keyed by `image_path`: one row per detected
        marker, `marker_id` + 4 corners x (x, y) in scene px. Separate file so
        `labels.csv` stays narrow and partial detections (2-3 markers) fit.
        Screen-side marker positions are static and already in `metadata.json`.
      - `labels.csv`: add `homography_reproj_px` (per-sample quality flag) and
        `screen_distance_mm` (null until scene intrinsics exist)
      - Depth = solvePnP on the stored corners (marker ~29.8 mm, from
        `SCREEN_PHYSICAL_MM` / pixel pitch) -> screen distance + pose. Raw
        corners let it be backfilled for every session once intrinsics exist.
      - Per sample, not per fixation, so head motion during capture shows up
      - Update `docs/dataset_format.md` + a test
- [ ] Eye↔scene extrinsics on the rig. Pin the eye mode first (Capture architecture):
      eye intrinsics only hold for one native mode + crop. Laser-print the
      `tiny` board for the eye side (sized for eye distance, no refocus) and
      pick a scene-side size, paste them on the jig, then run
      `calibrate_eye_intrinsics.py` and `calibrate_extrinsics.py`
- [ ] Sessions reference the rig calibration in `metadata.json`
      (`rig_calibration_id`, `extrinsics`, eye intrinsics; all null today). Do it
      after `timestamping` merges, since both change `persistence.py`
- [ ] After `timestamping` merges: move `_eye_cam_settings` /
      `_scene_cam_settings` out of `__main__.py` into a shared module (the
      calibration scripts import them from `__main__` for now), and drop
      "(planned)" from the `rig_calibrations` heading in `docs/dataset_format.md`
      (left alone here to avoid a merge conflict)
- [ ] Multi-pose coverage at steep head angles: live marker count as pose
      guidance, then more border markers so any 4 well-spread ones work
      (`TODO_multipose_coverage.md`)
- [ ] Parallax model: calibrate at 2+ depths, use the eye-to-scene offset to
      correct gaze for a given depth (needs a runtime depth source: assumed,
      scene depth, or vergence from a second eye cam)
- [ ] Slip robustness: reintroduce the glint as a pupil-CR reference, or a
      quick 1-point drift correction before each use

## Housekeeping

- [ ] Eye cam resets / drops off USB often (~25x on 2026-09-23, incl.
      `can't read configurations, error -71`), worse through passive USB
      extension cables. Try a powered hub near the headset / short or active
      cables. Capture code should also survive a reset (reopen by USB id).

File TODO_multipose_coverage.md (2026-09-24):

# TODO: Multi-pose calibration coverage + guidance clarity

Two follow-up ideas for why multi-pose ('m') calibration gets hard at extreme
head angles. Not started yet: this is a working spec to pick up later. It
builds on the calibration UX work (merged in PR #28) and on the undistorted
homography (`use-intrinsics-for-homography`, see `TODO.md`).

## Root cause for this doc's two items

Scene cam horizontal FOV is genuinely narrow: `fx=1894.7px` at 1920px width →
`2·atan(960/1894.7) ≈ 54°` (computed from `scene_intrinsics.json`). Neon's
scene cam is 130°+ specifically to avoid this class of problem. Multi-pose
calibration (`'m'`) asks the user to turn their head while keeping all 4
corner ArUco markers in frame simultaneously — past some turn angle that's a
hard physical constraint, not a tuning problem.

Also worth remembering: `'d'` (detailed) is single-pose, eyes-only — no head
movement is supposed to happen there at all. If "what angle do I look at" is
being asked about `'d'`, the actual answer is "don't turn your head"; these
two items are about `'m'` specifically.

## 1. Tie multi-pose guidance to the live marker HUD (cheap)

**Problem:** `CALIB_POSE_GUIDANCE` (`config.py`) gives blind qualitative
instructions — `"turn your head LEFT, keep looking at the screen"` — with no
feedback for how far is far enough, or too far. The user has to guess, then
find out only when a fixation stalls/times out that they overshot.

**Fix:** `ArucoHomography.last_found_ids` and `last_marker_count` (added in
`calibration-update`) already drive the overlay's per-corner status rings.
The pose-break screen (`TkCalibrationOverlay._render_pose_break`, and
`CalibrationRoutine.next_pose_guidance` in `routine.py`) could reuse that
same live signal instead of static text — e.g. append "(currently Y/4
markers visible)" to the guidance string during the pose break, or phrase the
guidance itself around the feedback: "turn left until a marker just starts to
drop, then ease back." This makes the existing rings double as the angle
guide instead of adding new UI.

Small, self-contained, no architecture change — good first PR for this file.

## 2. Don't require the 4 specific corner markers (bigger lift)

**Problem:** `compute_homography`/`_homography_from` hard-require all 4 of
`ARUCO_IDS` (`aruco_homography.py`, `_homography_from`: `if any(i not in
id_to_center for i in self.marker_ids): return None, None`). At a real head
turn, one corner marker physically leaves the narrow-FOV frame before the
others — so multi-pose's actual usable turn range is capped by whichever
corner marker clips first, not by the lens' overall FOV.

**Fix direction:** add markers at edge midpoints (8 total anchors around the
screen border, in `screen_anchor_points()`/`quiet_zone_origins()`), and let
the homography solve from any 4+ visible, well-spread markers rather than a
fixed set of 4. This raises the actual usable head-turn range independent of
the lens — the constraint becomes "4 of 8 markers visible" instead of "4 of
4," which is a much easier bar to clear at a steep angle.

**Scope/complexity, be honest about this before starting:**
- Marker layout changes touch `config.py` (`ARUCO_IDS`, quiet zone
  geometry), `screen_anchor_points()`/`quiet_zone_origins()`, the Tk
  overlay's corner-drawing code (`_draw_aruco_corners`), and probably the
  ring HUD's quadrant-arc mapping (`_draw_active_indicators` in
  `tk_overlay.py` currently hardcodes 4 quadrants from `ARUCO_IDS`).
- `cv2.findHomography` wants ≥4 points but doesn't care which corners they
  come from — the real work is: (a) picking a "well-spread enough" subset
  policy (4 markers clustered in one half of the screen give a much worse
  extrapolated fit than 4 spread around the perimeter — this is the same
  class of edge-bias problem the undistortion branch just fixed, so don't
  reintroduce it here), and (b) deciding what "good enough spread" means
  quantitatively.
- Alternative considered and rejected for now: solvePnP from a single
  marker's 4 corners (no need for multiple markers) — noisier, since one
  small marker's corners are tightly clustered in a small image region and
  any pixel noise blows up over the full extrapolated homography. Multiple
  spread-out markers is the more robust direction.

Not scoped into a branch yet — needs its own design pass on the "which
markers, how many, how to pick a well-spread subset" question before writing
code.

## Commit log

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2026-03-06 Overhaul calibration: 12-point polynomial regression, multi-sample capture, save/load
    Replace 5-point homography with 12-point (3x4 grid) 2nd-degree polynomial
    regression for better accuracy and nonlinear distortion handling. Each
    calibration point now collects 15 frames and uses the median gaze vector,
    rejecting high-variance captures. Adds leave-one-out cross-validation error
    reporting, save/load calibration to disk, and session data accumulation for
    future ML training. Also optimizes get_darkest_area() with vectorized OpenCV
    ops and removes per-frame gaze_vector.txt file I/O.
2026-03-06 Add PCCR eye tracker: replace 3D sphere model with pupil-glint vector
    New file based on 3DEyeTracker.py. Removes all 3D model code (sphere
    center estimation, ray-sphere intersection, rotation matrices) and
    replaces with Pupil Center - Corneal Reflection approach: detect IR
    glints near pupil, compute simple 2D (pupil - glint) vector that feeds
    into the existing polynomial calibration. Head-movement invariant by
    design since pupil and glint shift together.
2026-03-06 Fix bugs, remove dead code, and minor cleanup in PCCR eye tracker
    - Fix optimize_contours_by_angle: normalize vectors before dot product comparison
    - Fix _detect_pupil_adaptive: compute area bounds from ROI size, not full frame
    - Scale mask size with frame width instead of hardcoded 250px
    - Replace list.pop(0) buffers with collections.deque(maxlen=...)
    - Remove dead code: gaze_buffer, fit_and_draw_ellipses, axes_lengths, unused params
    - Comment out HIGH_FPS_MODE double-blur with TODO
2026-03-06 Add glint geometric validation and close UDP socket on exit
    Reject spurious second glint when inter-glint distance doesn't match
    expected IR LED hardware spacing. Close UDP socket in both exit paths
    to prevent port binding errors during rapid restarts.
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2026-04-21 Add pupil-only eye tracker (Pupil Labs approach)
    Fork of EyeTracker_PCCR.py that drops glint detection and maps pupil
    center directly to scene-camera coords via the same bivariate polynomial.
    Based on Kassner/Patera/Bulling 2014 (arXiv:1405.0006).
    v1 reuses the existing blob -> ROI adaptive-threshold -> fitEllipse
    detector; Swirski-style edge-based detection is the planned v2 upgrade.
    Adds a circularity-based confidence gate (surfaced from the refiner) and
    an outlier-rejection buffer on pupil position. Saves to a separate
    calibration_pupil.npz so it doesn't clobber the PCCR calibration.
    Co-Authored-By: Claude Opus 4.7 (1M context)
2026-04-21 Port pupil detector to Świrski / Pupil Labs pipeline
    Replaces the blob + local-ROI adaptive-threshold detector with the
    edge-based algorithm described in Kassner/Patera/Bulling 2014:
    1. Haar center-surround (Świrski 2012) via integral image for initial
    pupil region estimation.
    2. Canny edges on the ROI.
    3. Intensity-based edge filtering — keep edges on dark-region
    boundaries (1st-percentile + offset as dark cutoff), drop edges
    near spectral reflections (near-saturated mask, dilated).
    4. Curvature-continuity split: tangent-direction dot-product gate
    breaks contours at corners.
    5. Candidate ellipses fit per sub-contour with si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
2026-04-30 Add heatmap visualization tool to scripts/extras
    Transplants scripts/heatmap.py from the abandoned lint-fixes branch into
    scripts/extras/heatmap.py, alongside the other auxiliary tools. The file
    is self-contained (cv2/numpy/time/os only) and adds no callers in the
    eyetracker package.
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2026-05-05 Fixed calibration game
    - Calibration game went fullscreen, best score was not tracked, time never reset, final score never updated.
    - Fixed all of the above and made the grid remain as-is for the entire process
2026-05-05 Fixed calibration game + implemented heatmap
    - Reverted game to original fullscreen display when active. Kept fixes to score, best score, etc.
    - Created Heatmap
2026-05-06 Replace MA smoother with 1€ filter for adaptive gaze smoothing
    Fixed-window moving average forces a single noise/lag tradeoff. The 1€
    filter (Casiez et al., 2012) raises the low-pass cutoff with signal
    speed, so fixations get heavy smoothing while saccades pass through
    with little lag. Drop-in: same add()/reset() interface; uses
    time.monotonic() internally so callers don't need to pass timestamps.
    Replaces GAZE_BUFFER_SIZE with GAZE_MIN_CUTOFF / GAZE_BETA / GAZE_D_CUTOFF.
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2026-05-22 Small README fix
    Claude accidentally used raspberry pi instead of Jetson for a milestone step
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2026-05-22 Update README docs
    Summary of changes
    - README.md — ArUco wording fixed in two places (now says "drawn on the laptop screen", not pinned/printed)
    - frontend/README.md — replaced the create-next-app boilerplate with project-specific install/run, Supabase env vars (with a note
    that the service-role key must never go in a NEXT_PUBLIC_* var), and the backend dependency
    - scripts/eyetracker/README.md — new backend component README, mirrors the root content for install/run/controls/layout
    - frontend/.env.local.example — placeholder template with a comment warning against putting the service-role key in there
    - .gitignore — added !.env.local.example exception so the template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
2026-05-22 Switch to webpack to fix filepath issues
    @tailwindcss/postcss 4.2.2 has a buggy fallback when its caller
    doesn't pass from: it computes the resolver base as
    path.dirname(path.resolve("")), which strips one segment off
    your cwd — so running from frontend/ made it look for
    tailwindcss in eye_tracker/. Switching next dev to use
    --webpack bypasses Turbopack's PostCSS integration (which is
    what wasn't passing from), so the plugin gets the correct file
    path and resolves tailwindcss from frontend/node_modules as
    expected.
2026-06-06 Migrate calibration/session persistence from .npz to JSON + CSV
    The .npz layer was doing three ill-fitting jobs: structured metadata (forced
    cast/pickle on load), an append-only history (full read-rewrite, ragged object
    arrays), and raw samples triple-stored across calibration/history/labels. Move
    each to a format that fits, as the foundation for the hardware-agnostic data
    pipeline feeding the eventual CNN.
    - Model: calibration_pupil.npz -> calibration.json (coeffs + degree + sizes +
    source_session; raw samples no longer duplicated here)
    - Per-session record: new session_<ts>/metadata.json — self-contained dataset
    record inlining scene intrinsics, with null placeholder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
2026-07-15 Add parametric OpenSCAD mount for UC-844 eye camera
    Pocket-frame with a tight registration zone plus a looser lead-in
    zone locates the 38x38mm PCB by its edges to fix the looseness of
    the old mount, with 4 corner heat-set-insert bosses/gussets to bolt
    the board down and a perforated floor for airflow (per 3d-files/NOTES.md).
    Reuses two properties measured directly from the old mount's real
    STEP file (3d-files/bottom mount/v1 various internal eye cams.step):
    the 60 degree camera tilt, and the glasses-attachment clip's snap-fit
    keyhole slot geometry (mouth/neck/pocket widths + bolt hole).
    Parameters are grouped by confidence (measured from STEP vs. from
    photos/ruler vs. designer defaults) so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
    [uc844_mount_v1.scad]
2026-07-15 Fix camera orientation and rework frame as an open picture-frame
    Camera tilt was flipped so the pocket opening (where the PCB/lens
    faces) tilts back toward the spine and glasses clips - inward toward
    the eye - instead of outward away from the face.
    Frame is now a genuine open picture-frame (thin rim hugging the PCB
    edges, hollow in the middle) with a diagonal-braced pad at each
    corner carrying the mounting screw, instead of a solid slab. This
    makes the back-perforation workaround unnecessary since there's
    nothing solid left to perforate - airflow is inherent to the design
    now. Added an explicit connector tab so the spine still fuses solidly
    into the frame despite the hollow middle (verified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
    [uc844_mount_v1.scad]
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2026-07-15 Fix dip direction in v2 mount (was raising the lens, not lowering it)
    dip_angle and tilt_angle both rotate about the same axis, and the dip
    was applied with the same sign as the tilt, so it compounded the
    tilt instead of counteracting it - moving the lens further up/out
    rather than back down. Traced the actual centroid coordinates through
    both rotations to confirm: at dip_angle=25 the old (buggy) sign put
    the frame centroid at height 32.0 (higher than v1's 23.8); the fixed
    sign puts it at 11.7 (lower, as intended). Volume-check on the STL
    still confirms a single fused part after the fix.
    Also documented that the old mount's STEP file can't supply ground
    truth for how much dip is actually ne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
    [uc844_mount_v2_dipped_spine.scad]
2026-07-15 Solve v2's dip_angle from a real lens-height measurement
    The old camera's lens sits ~3/8in (9.5mm) above the clip. Solved for
    the dip_angle that puts this frame's PCB/lens centroid at the same
    height above the clip while holding tilt_angle fixed at 60 degrees
    (matching the old mount, per the user's requirement) - 29 degrees,
    up from the earlier placeholder guess of 25. Verified the centroid
    math directly (root-solved against the same transform chain used to
    catch the previous sign bug) and re-confirmed the part still fuses
    into one manifold solid after the change.
    Claude-Session: https://claude.ai/code/session_01KF1U5JFzBcD4CbzqbnSUAs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
    [uc844_mount_v2_dipped_spine.scad]
2026-07-15 Confirm hole_pitch=34 against a sharp photo (was an unverified guess)
    A clearer board photo showed two nested corner-hole patterns, not one
    real + decoys as originally assumed from a blurrier shot. Measured
    both via circle detection (cross-checked against all 4 sides of each
    square): outer holes at 34.0mm pitch, inner at 28.0mm - matching the
    "compatible with 34x34, 28x28mm" note from the very first message.
    hole_pitch=34 already targeted the outer pattern correctly, so no
    functional change, but the confidence label and comments were wrong
    (claimed only 4 real holes existed) and are now corrected. Also
    tightened hole_dia to the measured 2.85mm (from a rough 3.0mm guess);
    purely informational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
    [uc844_mount_v1.scad, uc844_mount_v2_dipped_spine.scad]
2026-07-20 Fix protruding wedge at the spine joints (v2)
    The two spine bends were fused by extending each segment past the
    joint by a fixed 2mm overlap - fine for the unrotated clip-to-spine
    joint, but wrong at the two angled bends: since the mating faces
    aren't coplanar once rotated, the extension pokes a wedge out past
    the neighboring segment's surface instead of meeting it flush. Traced
    the exact numbers: at the tilt joint, the frame's connector tab's
    real face and the spine's real end face were ~1.9mm apart, closed
    only by the tab overlapping sloppily at the 60 degree angle - that
    gap was the protruding wedge visible in Cura that made "lay the frame
    flat" seem impossible.
    Replaced both joints with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
    [uc844_mount_v2_dipped_spine.scad]
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2026-07-20 Fix two real defects in the glasses rod adapter
    The printed part came out broken (thin, hollow, fragile prongs where
    the screw bosses and pegs should have been) - traced to two separate
    design bugs, not a print-orientation issue:
    1. The rod channel was centered on the same axis as the screw bosses
    and ran the FULL length of the clamp, cutting straight through both
    insert bosses and leaving only thin crescent-shaped remnants instead
    of solid cylinders. Shortened the channel (12mm, centered) and moved
    the screw bosses further out (offset 13mm) so their Y-ranges no
    longer overlap at all - verified analytically (channel now spans
    Y -6..6, bosses start at Y=9.5, a clean 3.5mm g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
    [glasses_rod_adapter.scad]
2026-07-20 Add v3 mount with integrated rod clamp (replaces peg adapter)
    Fold the glasses-rod attachment directly into the mount instead of
    bridging it with a separate two-piece peg adapter. The near end of the
    spine is now the lower half of a screw clamp; a small separate cap is the
    upper half. The oval glasses rod (measured 5x4mm) is sandwiched between
    the two half-oval channels and pinched by two screws (fore and aft of the
    rod) driven into heat-set inserts in the base - the same insert scheme
    used at the four camera-mounting corners.
    This removes the confusing extra peg-into-keyhole interface entirely: the
    glasses connect straight to the mount, one clamp, no loose rotational DOF.
    Includes a rod mo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
    [uc844_mount_v3_rod_clamp.scad]
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2026-07-21 Make the rod clamp forgiving to rod-size measurement error
    Previously the two clamp halves had flat mating faces and a bore sized to
    the rod plus clearance, so tightening bottomed the faces against each
    other and left a fixed-size cavity - if the real rod were any smaller than
    the 5x4mm estimate it would rattle and tightening wouldn't help.
    Undersize the bore in the split (Z) direction (channel_r_z = rod_z/2 -
    clamp_bore_squeeze) so the rod always stands proud of the parting line and
    the halves pinch the ROD, never bottoming out flat first. A rod-size error
    now just changes the leftover gap between the halves, not whether it grips:
    tolerates ~1mm thinner (down to zero gap) and several mm th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
    [uc844_mount_v3_rod_clamp.scad]
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2026-07-22 Add scene-camera top mount that locates the PCB on its own holes
    The current scene-camera bar retains the HQ-L103 PCB with press-fit
    windows, so the board shifts and doesn't seat consistently. This new
    backing mount instead:
    - locates the board with a full-perimeter pocket (no slide/rotate)
    - pins it with two posts through the board's own end mounting holes
    - holds it flat with chamfered snap post-heads + two connector-end lips
    - opens a center window for component clearance and airflow (NOTES.md)
    The clip interface (two Ø3.2 mm holes at 64 mm pitch) was extracted from
    the existing top-mount STEP files, so the current white rod clips bolt on
    unchanged. Fully parametric; PCB dimensions are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
    [scene_cam_top_mount_v1.scad]
2026-07-22 Set scene mount to measured PCB size (62 x 9 mm)
    Use the real board footprint (62 x 9 mm) instead of the photo estimate.
    Separate the bare-board edge thickness (pocket/snap/lip depth) from the
    overall 5.68 mm module height, since the lens/components face forward and
    stay exposed rather than recessing into the plate.
    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
    [scene_cam_top_mount_v1.scad]
2026-07-22 Rework scene mount: datasheet dims, screw-down, L-tab clip ears
    Incorporate the manufacturer datasheet and the current bar's STEP interface:
    - PCB set to datasheet values: 62 x 9 x 1.0 mm; two Ø2.2 mounting holes
    4.0 mm apart, 2.0 mm from the end (camera 32.5 mm from that end).
    - Retention switched to screw-down: two M2 screws through the board's own
    mounting holes clamp it flat (self-tap pilots, or heat-set option).
    - Replicate the clip interface from the current bar's STEP: a rounded L-tab
    ear at each end carrying a Ø3.2 clip hole at 64 mm pitch, so the existing
    white rod clips bolt on unchanged.
    - Add a connector/cable relief at the connector end and keep the center
    airflow w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
    [scene_cam_top_mount_v1.scad]
2026-07-22 Enable third mounting hole for a 3-point clamp
    Turn on the connector-end Ø2.2 mounting hole so the board is screwed down
    at three points (two at the camera end, one at the connector end) instead
    of cantilevered off one end. Offset it ~2 mm from the width centerline per
    the datasheet, and stop the airflow window short of it so the screw has a
    solid seat. Offset is parametric (third_y_offset) for test-fit.
    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
    [scene_cam_top_mount_v1.scad]
2026-07-22 Open the connector end for USB plug clearance; fix connector mock
    The connector (like the camera/LED/MIC) is on the front side; the plate
    sits behind the bare PCB back and never touches it. Enlarge the
    connector-end relief into a fully open cutout so the USB plug can be
    inserted and the cable routed out. Also fix the connector stand-in in the
    PCB mock (it was drawn off-center) and add a plug/cable stub so the render
    shows the space the connector needs.
    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
    [scene_cam_top_mount_v1.scad]
2026-07-22 Extend clip ears out 2mm for more rod clearance
    Increase clip_ear_drop 2.0 -> 4.0 mm so the clip holes sit further from
    the plate, moving the rod away from the board. Rework the ear as a rounded
    tab (hull from the plate edge out to the hole) so it stays fused to the
    plate at any drop distance.
    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
    [scene_cam_top_mount_v1.scad]
2026-07-23 Add eye-camera mount v4: rod-hugging clamp + tilt pivot
    Redesign of the UC-844 eye-camera mount to fix two issues found on the
    printed v3: the camera aimed too high and sat too far from the eye.
    Changes vs v3 (uc844_mount_v3_rod_clamp.scad):
    * Removes the 24 mm rigid spine that cantilevered the frame away and
    stacked three fixed angles (the overshoot). The frame now hangs right
    off the clamp on a short forked arm.
    * Rebuilds the rod clamp with a tight bore (small squeeze) so the two
    halves close on the rod instead of sitting a large gap off it (v3 bug).
    * New rod->frame joint is a friction clevis: a centered tab on the
    frame's back is captured between two fork prongs o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
    [uc844_mount_v4_pivot.scad]
2026-07-23 Move v4 pivot to a side rail; keep the PCB back fully open
    The first v4 cut fused a centered tab to the frame's back via a rib
    across the window. That encroaches on the PCB back, where the USB
    connector lives and where an open back helps heat dissipation.
    Rework so nothing touches the frame's back:
    * The pivot bracket now grabs ONE solid side rail of the picture frame
    at ~1/3 up (neck bonded down the rail's height). frame_body() is
    unchanged - no rib, no back tab.
    * All hardware (bracket disc, arm, clamp) sits BESIDE the frame along
    the rod axis, so the entire back stays clear.
    * Joint is a single-lap friction disc: frame bracket disc bears against
    the mount disc, one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
    [uc844_mount_v4_pivot.scad]
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2026-07-23 Add eye-camera mount v5: centered, back-open, thin-rod clamp
    v5 replaces v4's side-mount (which hung the frame ~30 mm off the clamp,
    past the ~1 inch of usable rod) with a centered, compact arrangement:
    clamp on the rod -> short rise arm DOWN -> friction tilt pivot (small
    clevis) at the frame's bottom edge -> frame hangs below the rod, tilted
    up so the centered lens aims at the pupil.
    * Nothing sits behind the PCB (pivot grabs only the solid bottom rail) -
    USB connector + heat stay clear; frame_body() unchanged.
    * Rod clamp retuned + shrunk for the thin rod (~2.75 x 5 mm).
    * Aim geometry is modeled in-scene from the measurements (pupil ~27 mm
    up, ~19 mm behind the lens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
    [uc844_mount_v5_centered.scad]
2026-07-23 v5: clear the sight line, accurate lens, closer nominal
    Address two issues found in review of the first v5 nominal:
    * The camera's sight line to the pupil clipped the clamp. Fix has two
    parts: (a) make the rod clamp ASYMMETRIC - both screws on the eye
    side (+X), world side kept thin - so it stays out of the sight line
    that rises on the world side of the rod; (b) retarget the nominal
    closer (~30 mm, tilt ~36 deg), which also lifts the lens tip above
    the clamp so the whole optical path clears. echo() reports
    tip->pupil 29.9 mm, axis 36 deg vs 35.4 deg needed (aimed at pupil).
    * Model the lens at its real datasheet size (Ø12 body, Ø14 front,
    15.86 mm long) inst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
    [uc844_mount_v5_centered.scad]
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2026-07-23 v6: flat-plate arm + real bolt joint; both parts manifold
    Iterate the 3-part mount toward printable + verified:
    * Arm remodeled from round struts to a single FLAT PLATE in the tilted
    plane through the clip-ears and frame pads -> lays flat on the bed,
    prints without support, still hangs below the lens/FOV.
    * Frame bottom lugs + arm pads now share a coaxial hole along the frame
    normal (M2.5 bolt + nut lap joint); fixed the earlier non-manifold
    frame (lugs now overlap the bottom border cleanly).
    * Frame + arm both CGAL-manifold (Simple: yes). Aim unchanged
    (echo: tip->pupil 30.0 mm, 38 deg, pointed at pupil); 70 deg FOV cone
    clears the arm/clips/rod.
    * Added show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
    [uc844_mount_v6_arm.scad]
2026-07-24 Add v7: two separate arms + real modeled clips
    New file (copied from v6, per the "major change = new version" rule; v6
    left intact). Fixes v6's one-piece arm passing THROUGH the frame and the
    hand-waved clip interface.
    * TWO separate arms (one per side): each has a clip-ear at the rod that
    mates the real white clip, a short body, and a pad lapping a NEW
    front-bottom frame lug. Arms stay in FRONT of / below the frame ->
    no collision (v6 bug fixed), open center for the lens, out of the FOV.
    * Real clip imported from bottom mount/*.step as clip_ref.stl; rotate
    ([90,0,0]) seats its U-channel on the rod; the clip-ear's Ø3.2 hole is
    coaxial with the clip's screw hole. Two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
    [clip_ref.stl, uc844_mount_v7_two_arm.scad]
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2026-09-24 Organize 3D mounts into current / archive folders
    - Current: eye_cam/uc844_mount_v9, scene_cam/scene_cam_top_mount_v2 (first commit of v2)
    - Archive earlier SCAD iterations and old Fusion STEP files
    - Replace NOTES.md with README.md listing current designs
    - Fix clip_ref.stl paths in archived v7/v8; fix v9 header label
    [clip_ref.stl, glasses_rod_adapter.scad, scene_cam_top_mount_v1.scad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]
2026-09-24 Track scene intrinsics as JSON and back up legacy calibration history
    - scene_intrinsics.json: the scene-cam K/dist the app reads (1920x1080,
    reproj RMS 0.32 px, calibrated 2026-05-04). Same values as the .npz it
    replaces; nothing reads the .npz anymore.
    - legacy_calibration_history.csv: 27 pre-migration calibration sessions
    (352 point pairs). Only surviving copy, so keep it in git.
    [legacy_calibration_history.csv]
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2026-09-24 Clean up stale docs and comments; add jig design and CLAUDE.md
    - Validation captures are sessions tagged phase=validation, not
    validation_*.npz: fix routine.py, config.py and the calibration docs
    - UVC cheat sheet: eye cam is the Arducam OV9281 with full exposure
    controls; the "uncontrollable AEC" notes were for the retired Sonix
    - Bring the calibration jig design over from calibration-jig (without the
    photos and planning doc); document it and add the extrinsics TODO
    - Track CLAUDE.md (was gitignored) with repo-wide working rules + context
    [calibration_jig.scad]
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2026-09-24 Describe the steel-sheet calibration jig; drop the unbuilt 3D-printed design
    - The jig is three stainless steel sheets at ~90° with pasted ChArUco boards,
    not the .scad design (never built; the hand-eye solver doesn't need its
    marker_positions.json). Removed 3d-files/calibration-jig/.
    - Docs no longer call the jig planned or 3D printed
    - TODO: record what porting calibrate_extrinsics.py / calibrate_eye_intrinsics.py
    needs (match the app's eye/scene frame geometry, JSON I/O, shared board specs)
    [calibration_jig.scad]
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
